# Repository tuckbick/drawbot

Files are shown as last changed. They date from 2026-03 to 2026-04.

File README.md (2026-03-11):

# DrawBot CoreXY Controller & Plotter

## Overview

DrawBot is a custom, ESP32-based controller board and large-format CoreXY pen plotter.

This project was built to scale up the traditional desktop plotter experience. By moving to a custom ESP32 PCB running FluidNC, this iteration eliminates the need for multiple microcontrollers and messy wiring, wrapping WiFi control, SD card hosting, and heavy-duty motor driving into one clean package.

## Project Planning

A "living document" used to keep track of the ongoing planning, component sourcing, and build progress for this project can be found here:

* **[DrawBot Planning Spreadsheet](https://docs.google.com/spreadsheets/d/1DZCe1eKOiRGR80yqyA4uuKFQJ7K6CPcNbJUIT71Rvy4/edit)**

## Inspiration

The first iteration of this build was heavily inspired by the amazing [Plottermap project by Volzo](https://volzo.de/posts/plottermap/).

Volzo's original electronics used a dual-Arduino Nano setup running [GRBL](https://github.com/gnea/grbl/wiki), with a co-processor to handle Stallguard endstops. Since the exact frame specs weren't provided, I reverse-engineered my best guess for the physical construction. For this next-generation build, I am keeping that same physical frame but completely overhauling the electronics to a single-board ESP32 solution.

## The Machine (Hardware)

The physical plotter is designed for large-scale artwork:

* **Frame:** 1m x 1.5m V-Slot extruded aluminum with 3D printed joints.
* **Workspace:** Comfortably accommodates canvases and paper at least 24" x 40".
* **Kinematics:** CoreXY motion system driven by standard belts, pulleys, and idlers.
* **Motors:** 2x NEMA 23 stepper motors for slinging the heavy X/Y gantry, and 1x NEMA 17 for the Z-axis pen lift.
* **External Peripherals:** Support for physical limit switches, a dedicated 24V laser attachment port, and a UART expansion port for future upgrades.

## The Electronics (Controller)

The custom KiCad PCB is designed to be a plug-and-play brain for the machine:

* **Microcontroller:** ESP32 (DevKitC-32).
* **Firmware:** Runs [FluidNC](http://wiki.fluidnc.com/en/home) (a next-gen port of GRBL), which easily handles the CoreXY kinematics and adds native support for TMC SPI configuration.
* **Connectivity:** The ESP32 provides WiFi for remote monitoring and control via a FluidNC web UI.
* **Storage:** An onboard Micro SD card reader hosts the G-code project files locally so your computer doesn't have to stay plugged in for a 10-hour plot.
* **Stepper Drivers:** 3x TMC5160 StepStick modules. These easily provide the juice needed for the NEMA 23 motors.
* **Clean Wiring:** The stepper motor phases are routed out through standard RJ45 jacks, allowing you to use cheap, shielded Cat6 Ethernet cables to wire up the gantry.
* **Power:** Runs on a single 24V power supply (split into motor, laser, and logic domains), stepped down to 5V/3.3V using an MP1584 buck converter.

## Repository Contents

* `/drawbot.kicad_pro` - Main KiCad project file.
* `/*.kicad_sch` - Hierarchical schematic files (Power Delivery, Microcontroller, Stepper Drivers, IO Connectors).
* `/drawbot.kicad_pcb` - The physical PCB layout.
* `/libs/` - Custom footprint and symbol libraries used in the design.
* `/pdf/` - Exported PDF versions of the schematic and PCB layout for quick viewing.

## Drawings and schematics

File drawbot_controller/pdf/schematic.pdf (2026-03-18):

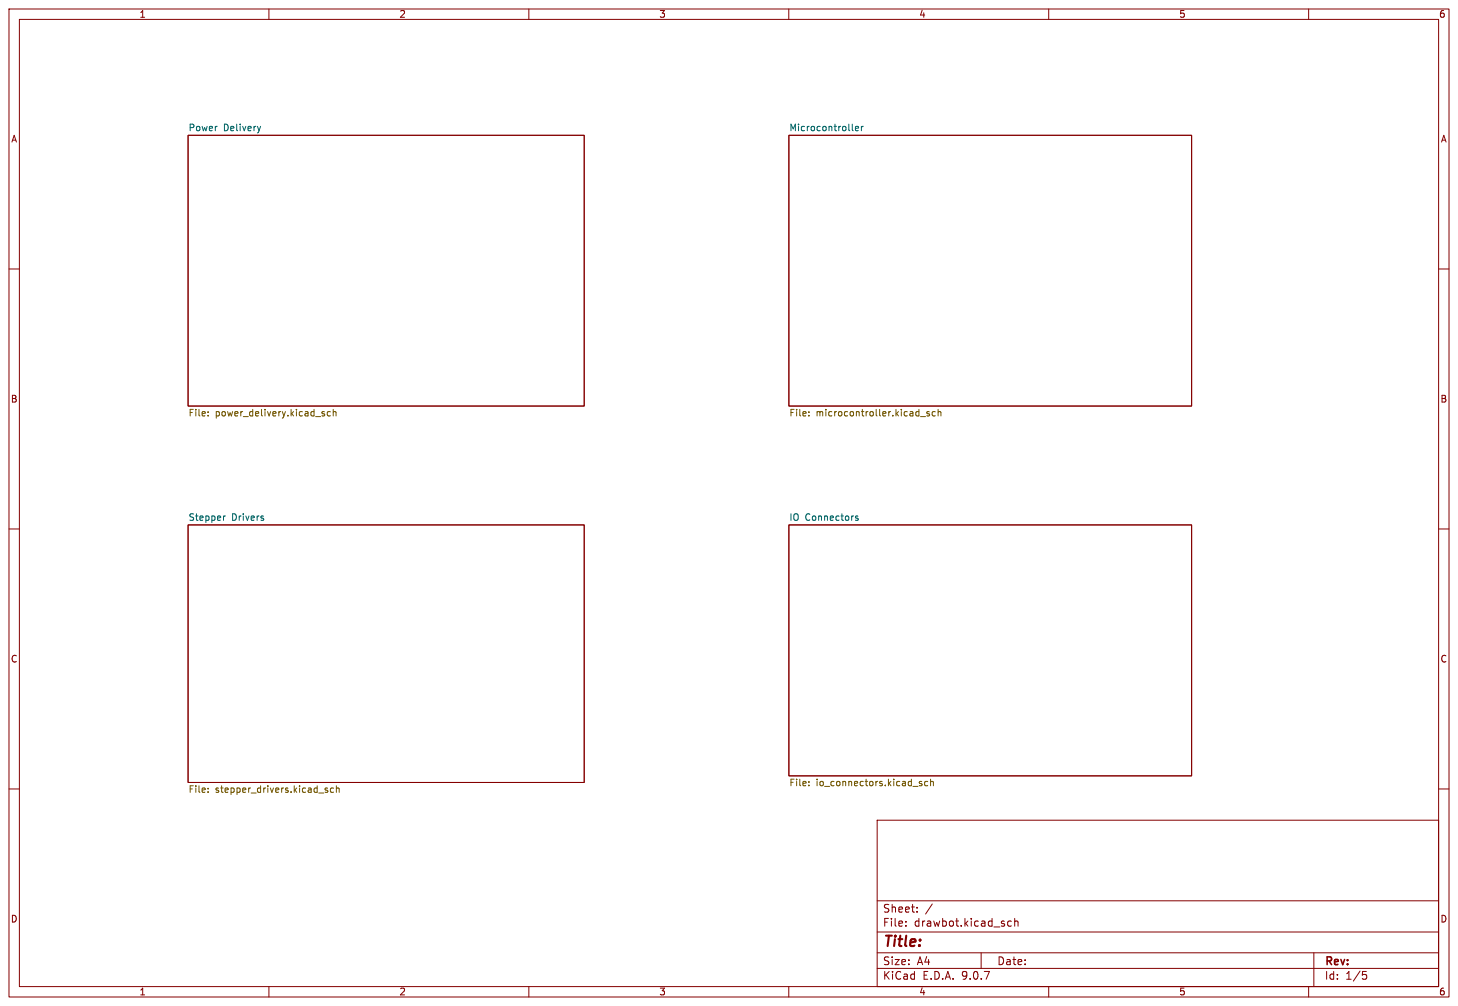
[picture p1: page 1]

IO Connectors File: io_connectors.kicad_sch Stepper Drivers File: stepper_drivers.kicad_sch

Id: 1/5 Title: File: drawbot.kicad_sch Sheet: /

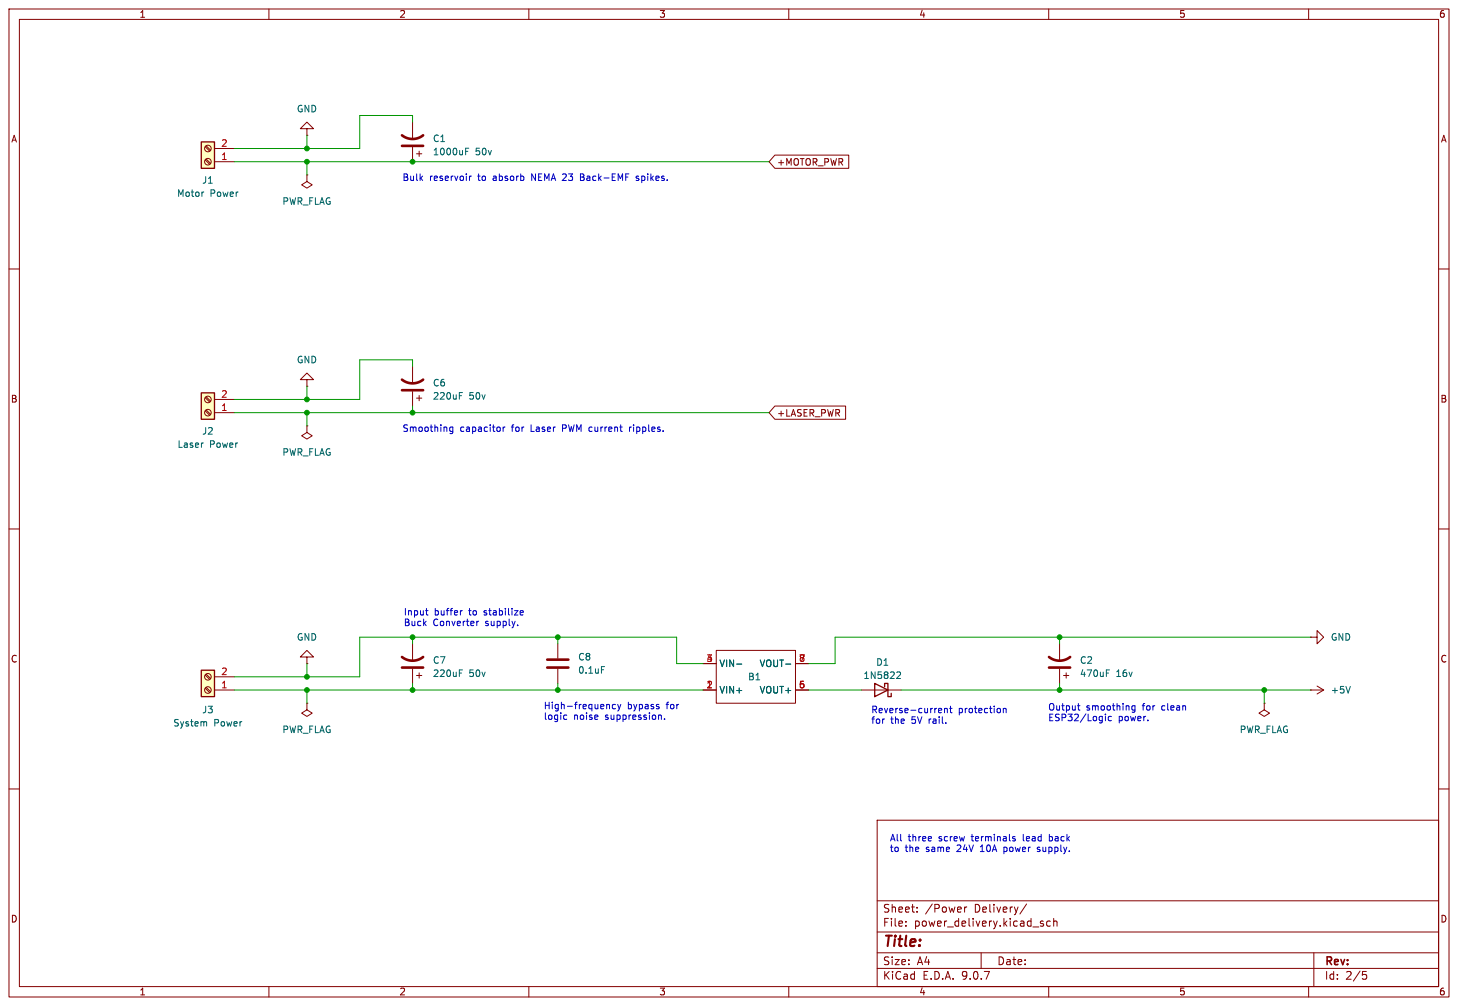
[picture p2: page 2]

Input buffer to stabilize Buck Converter supply.

to the same 24V 10A power supply.

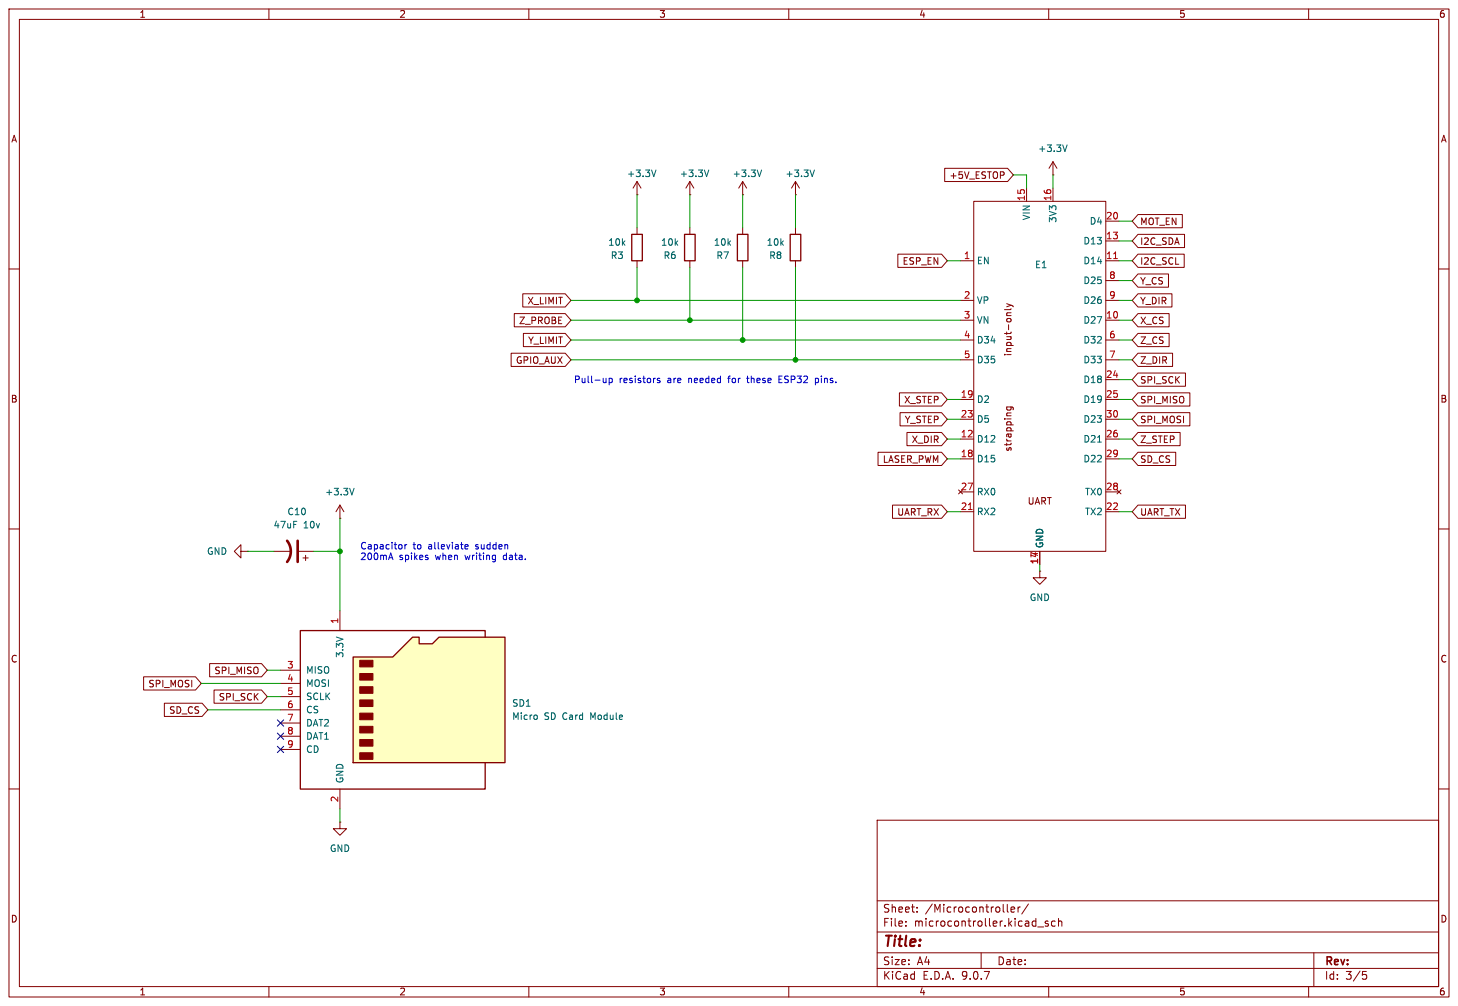
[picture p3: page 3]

Id: 3/5 Title: File: microcontroller.kicad_sch Sheet: /Microcontroller/ GND

2 SD1 Micro SD Card Module GND GND

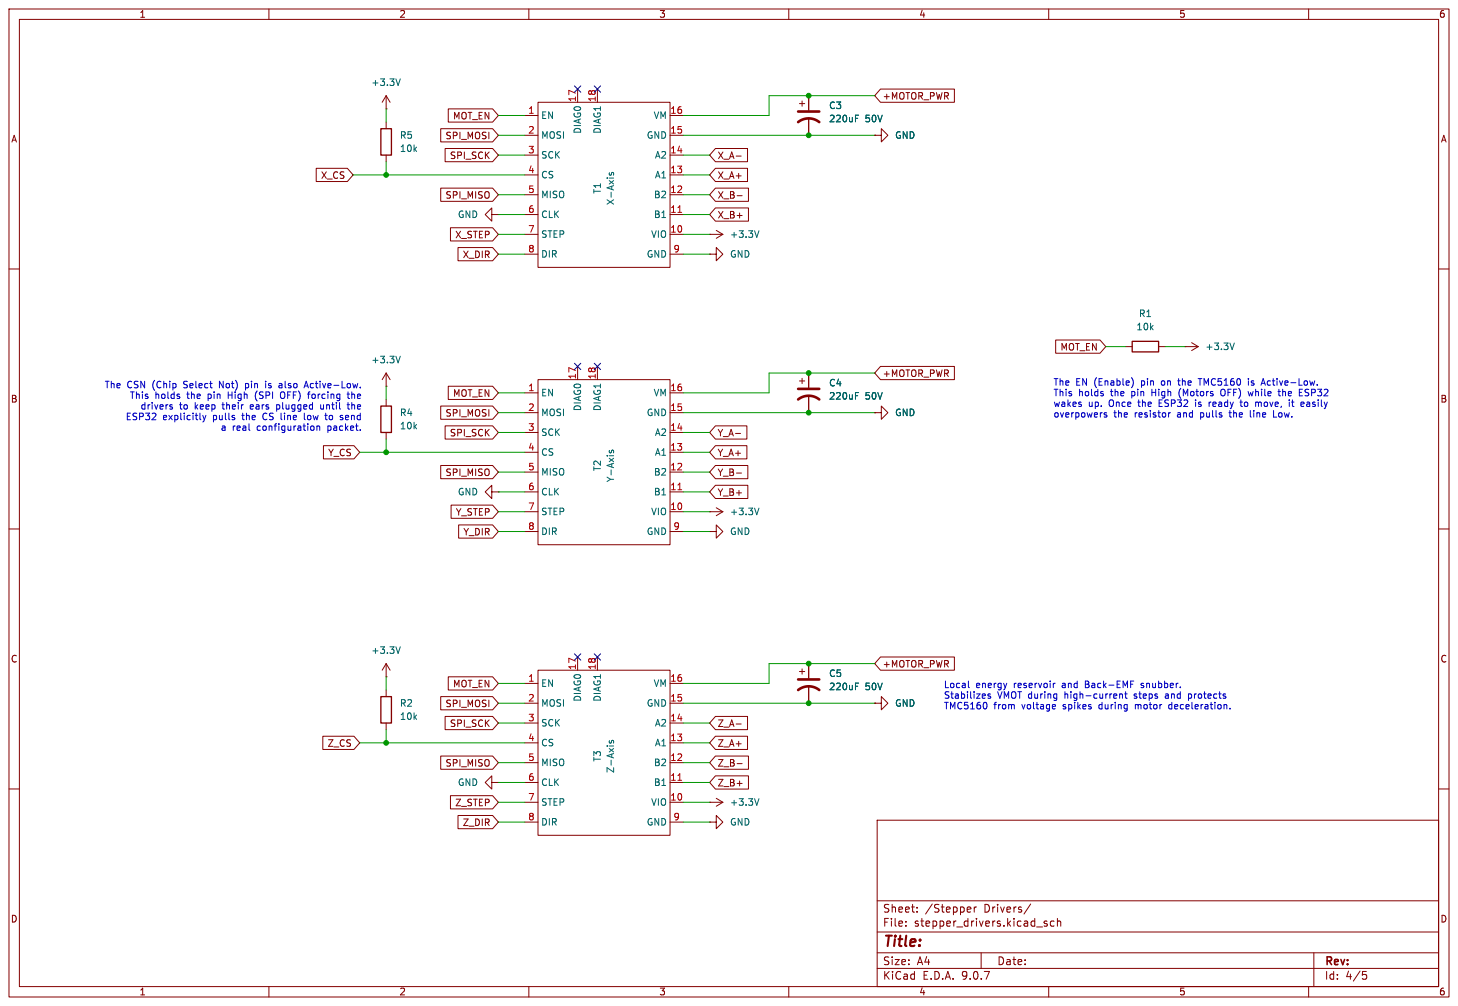
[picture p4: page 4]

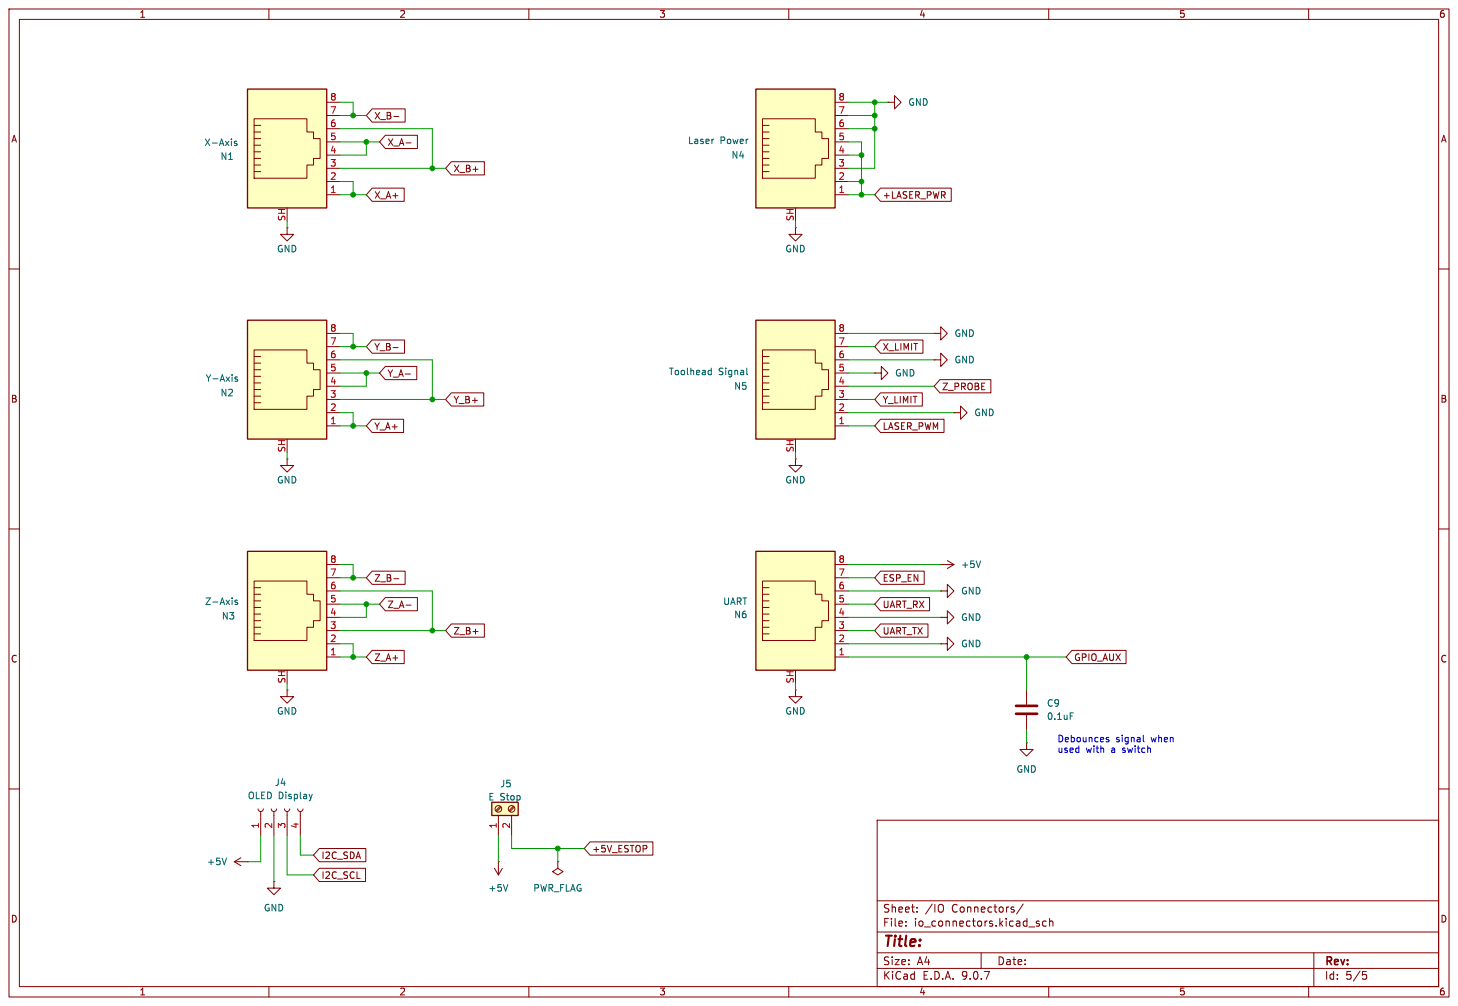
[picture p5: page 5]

Id: 5/5 Title: File: io_connectors.kicad_sch Sheet: /IO Connectors/ 1

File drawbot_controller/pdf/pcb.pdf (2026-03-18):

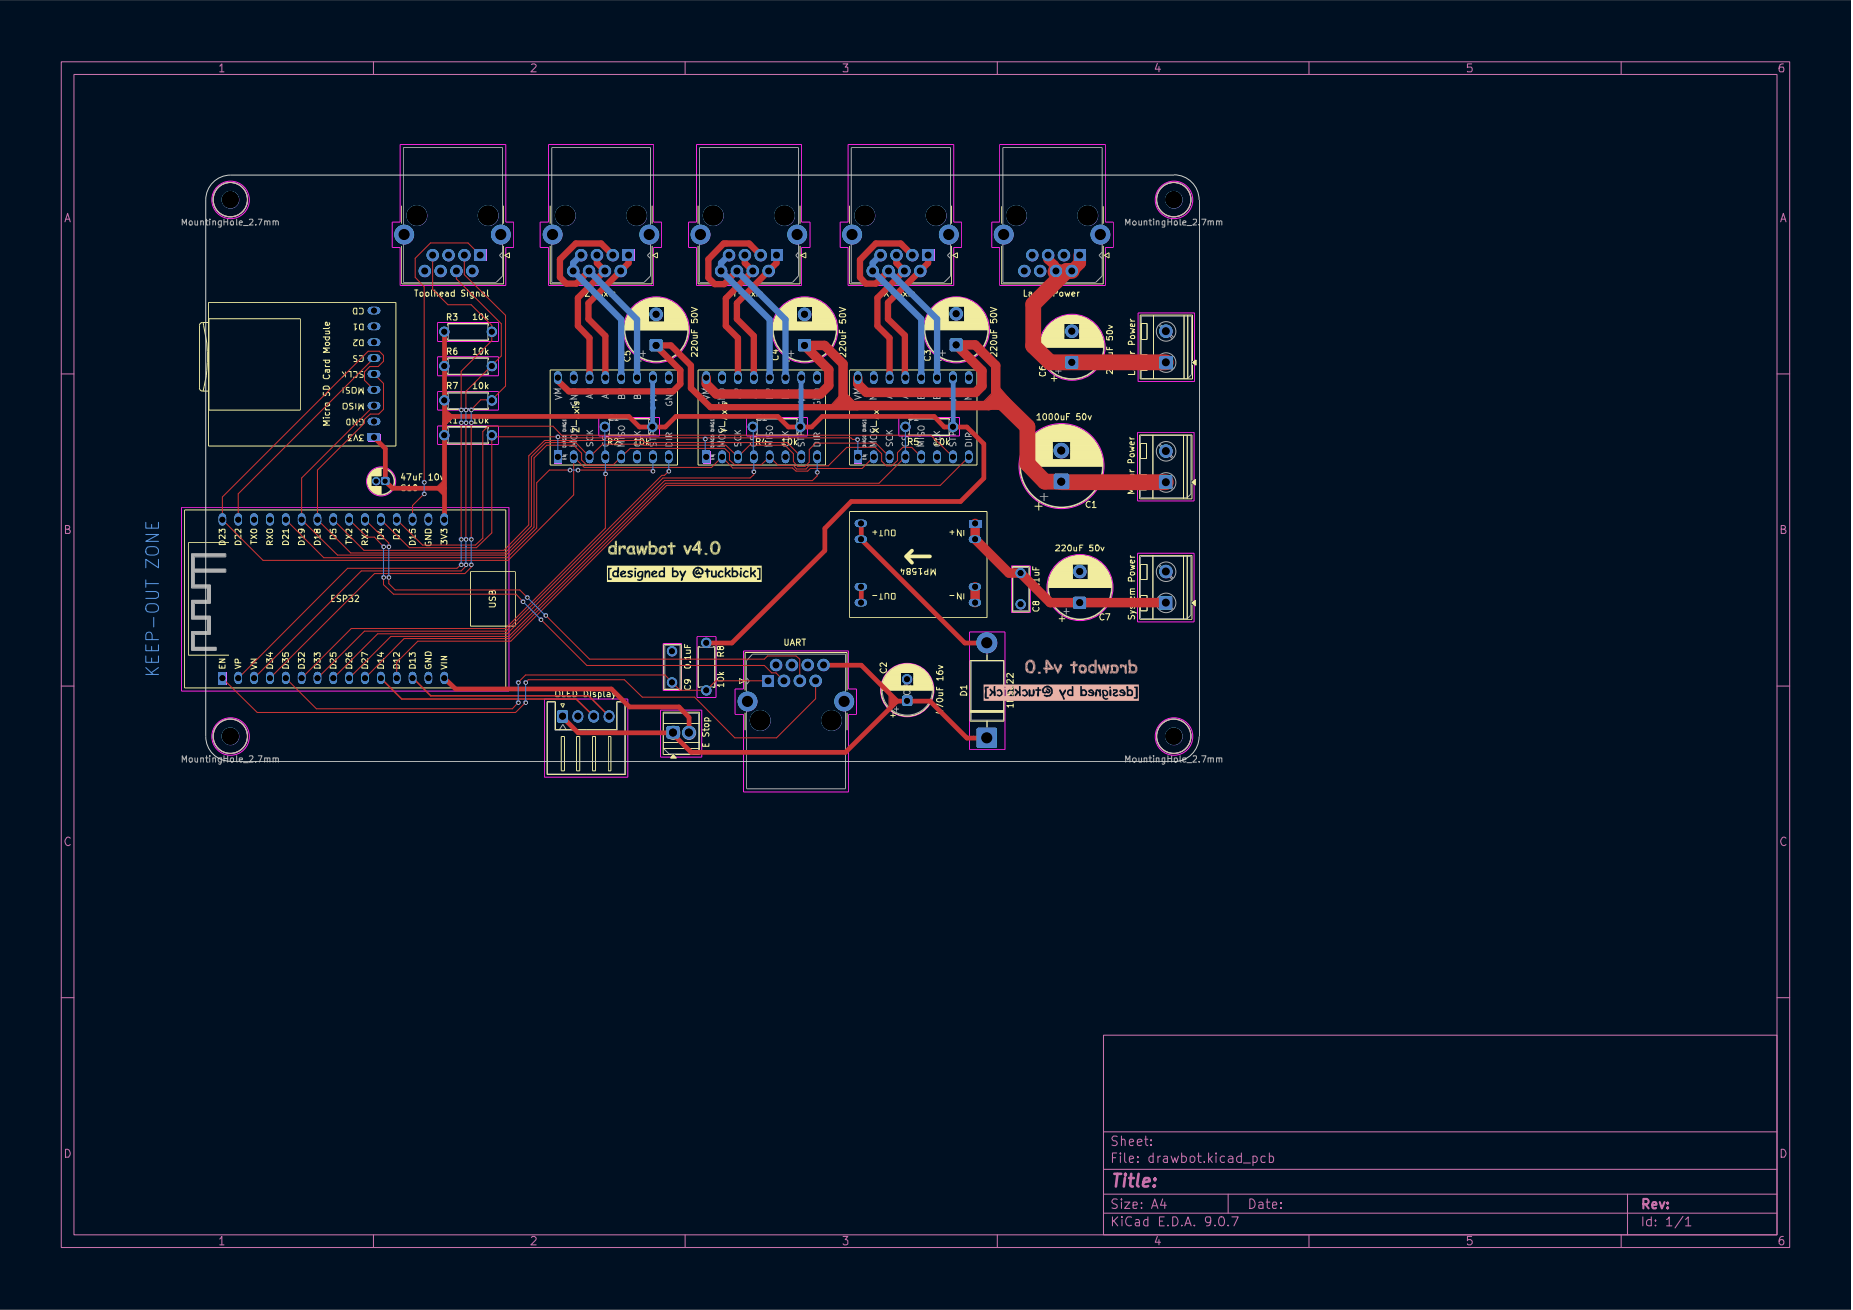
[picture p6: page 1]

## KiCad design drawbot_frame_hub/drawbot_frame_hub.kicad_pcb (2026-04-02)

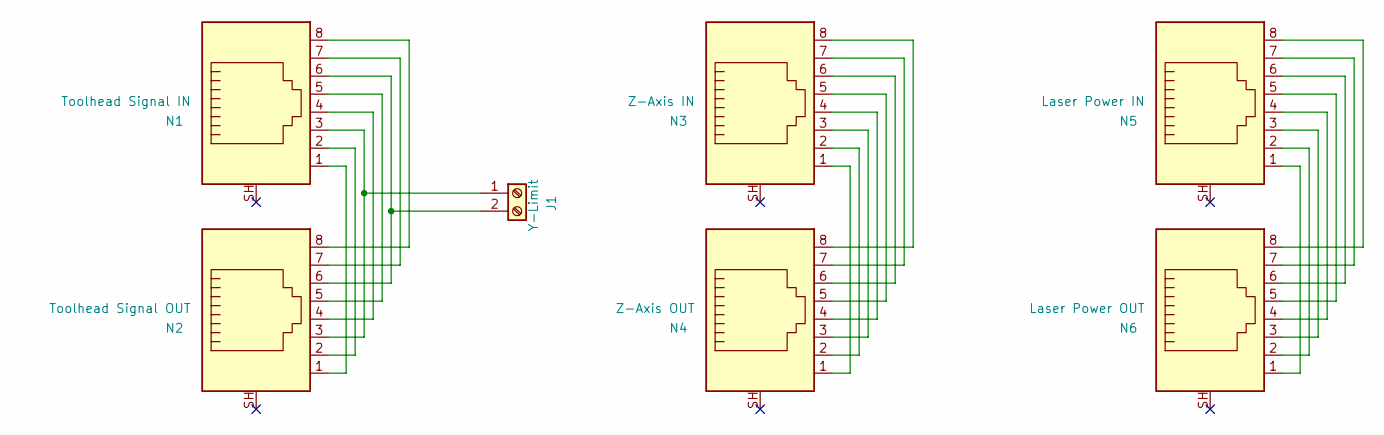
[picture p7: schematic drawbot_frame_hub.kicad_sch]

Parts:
J1: Y-Limit; TerminalBlock_Xinya_XY308-2.54-2P_1x02_P2.54mm_Horizontal
N1: Toolhead Signal IN; RJ45_HALO_HFJ11-x2450HRL_Horizontal
N2: Toolhead Signal OUT; RJ45_HALO_HFJ11-x2450HRL_Horizontal
N3: Z-Axis IN; RJ45_HALO_HFJ11-x2450HRL_Horizontal
N4: Z-Axis OUT; RJ45_HALO_HFJ11-x2450HRL_Horizontal
N5: Laser Power IN; RJ45_HALO_HFJ11-x2450HRL_Horizontal
N6: Laser Power OUT; RJ45_HALO_HFJ11-x2450HRL_Horizontal

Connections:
unnamed: J1.1, N1.3, N2.3
unnamed: J1.2, N1.6, N2.6
unnamed: N1.1, N2.1
unnamed: N1.2, N2.2
unnamed: N1.4, N2.4
unnamed: N1.5, N2.5
unnamed: N1.7, N2.7
unnamed: N1.8, N2.8
unnamed: N3.1, N4.1
unnamed: N3.2, N4.2
unnamed: N3.3, N4.3
unnamed: N3.4, N4.4
unnamed: N3.5, N4.5
unnamed: N3.6, N4.6
unnamed: N3.7, N4.7
unnamed: N3.8, N4.8
unnamed: N5.1, N6.1
unnamed: N5.2, N6.2
unnamed: N5.3, N6.3
unnamed: N5.4, N6.4
unnamed: N5.5, N6.5
unnamed: N5.6, N6.6
unnamed: N5.7, N6.7
unnamed: N5.8, N6.8

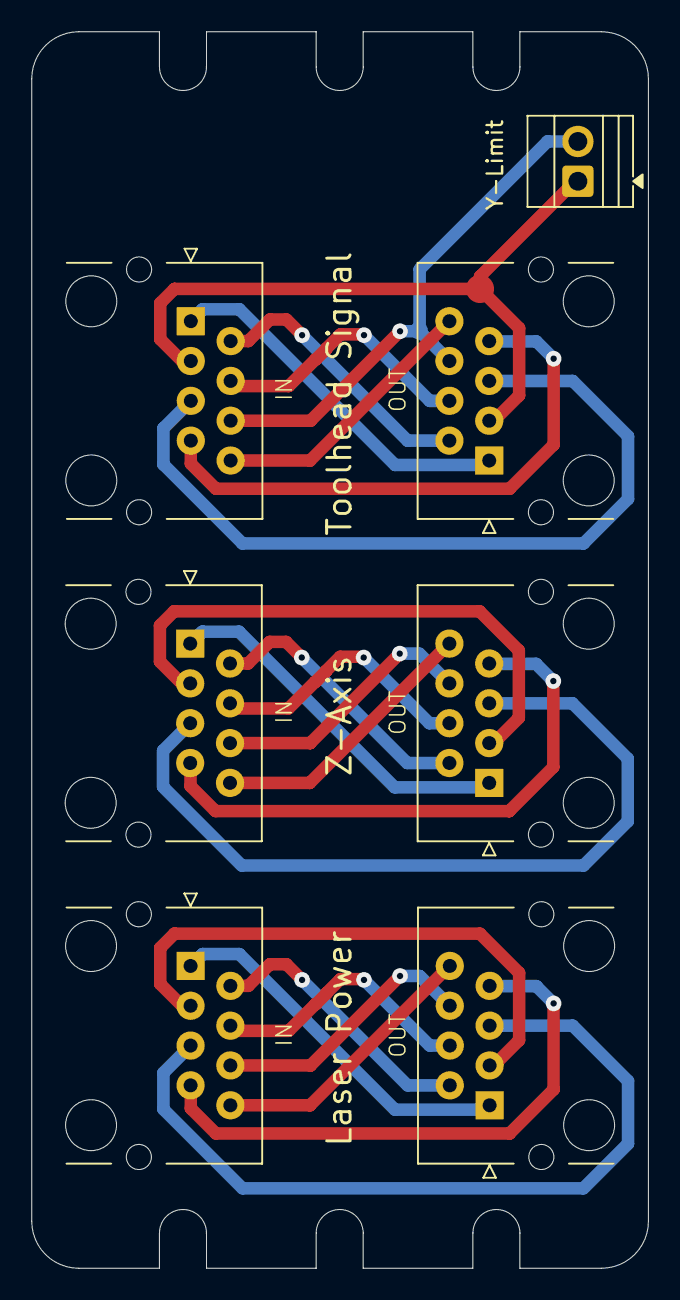
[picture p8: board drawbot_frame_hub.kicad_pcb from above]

Board: 2 copper layers, 39.3 x 78.9 mm, 7 parts (0 on the bottom side), 24 nets.

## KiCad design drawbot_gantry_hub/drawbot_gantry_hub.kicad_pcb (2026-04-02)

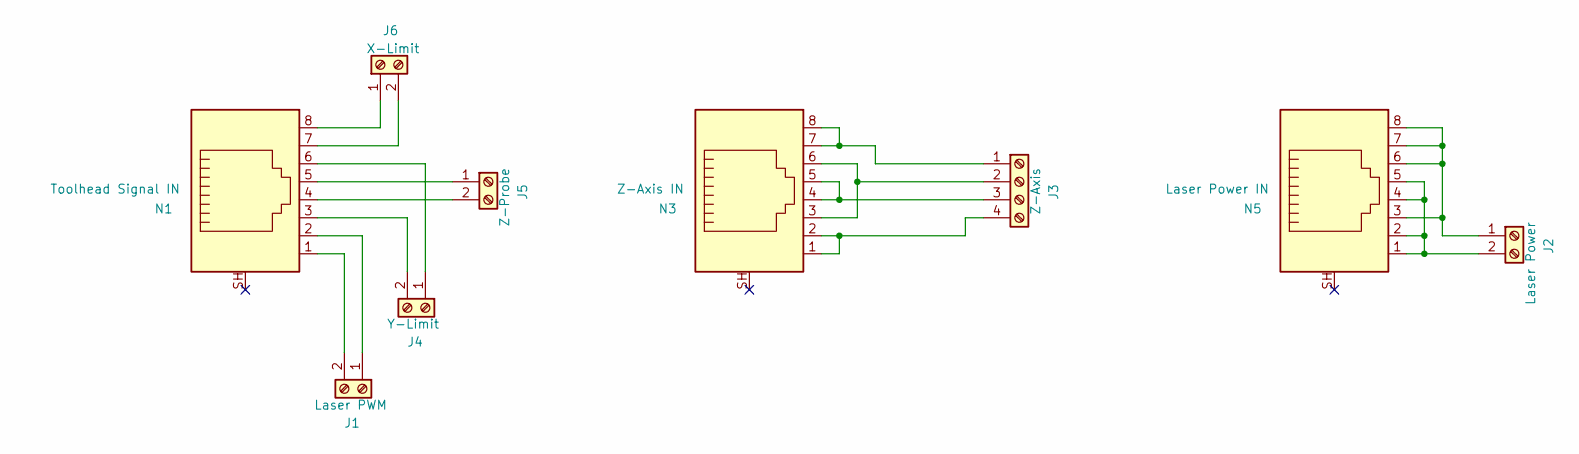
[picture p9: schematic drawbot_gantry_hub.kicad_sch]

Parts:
J1: Laser PWM; TerminalBlock_Xinya_XY308-2.54-2P_1x02_P2.54mm_Horizontal
J2: Laser Power; TerminalBlock_RND_205-00045_1x02_P5.00mm_Horizontal
J3: Z-Axis; TerminalBlock_RND_205-00047_1x04_P5.00mm_Horizontal
J4: Y-Limit; TerminalBlock_Xinya_XY308-2.54-2P_1x02_P2.54mm_Horizontal
J5: Z-Probe; TerminalBlock_Xinya_XY308-2.54-2P_1x02_P2.54mm_Horizontal
J6: X-Limit; TerminalBlock_Xinya_XY308-2.54-2P_1x02_P2.54mm_Horizontal
N1: Toolhead Signal IN; RJ45_HALO_HFJ11-x2450HRL_Horizontal
N3: Z-Axis IN; RJ45_HALO_HFJ11-x2450HRL_Horizontal
N5: Laser Power IN; RJ45_HALO_HFJ11-x2450HRL_Horizontal

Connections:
unnamed: J1.1, N1.2
unnamed: J1.2, N1.1
unnamed: J2.1, N5.3, N5.6, N5.7, N5.8
unnamed: J2.2, N5.1, N5.2, N5.4, N5.5
unnamed: J3.1, N3.7, N3.8
unnamed: J3.2, N3.3, N3.6
unnamed: J3.3, N3.4, N3.5
unnamed: J3.4, N3.1, N3.2
unnamed: J4.1, N1.6
unnamed: J4.2, N1.3
unnamed: J5.1, N1.5
unnamed: J5.2, N1.4
unnamed: J6.1, N1.8
unnamed: J6.2, N1.7

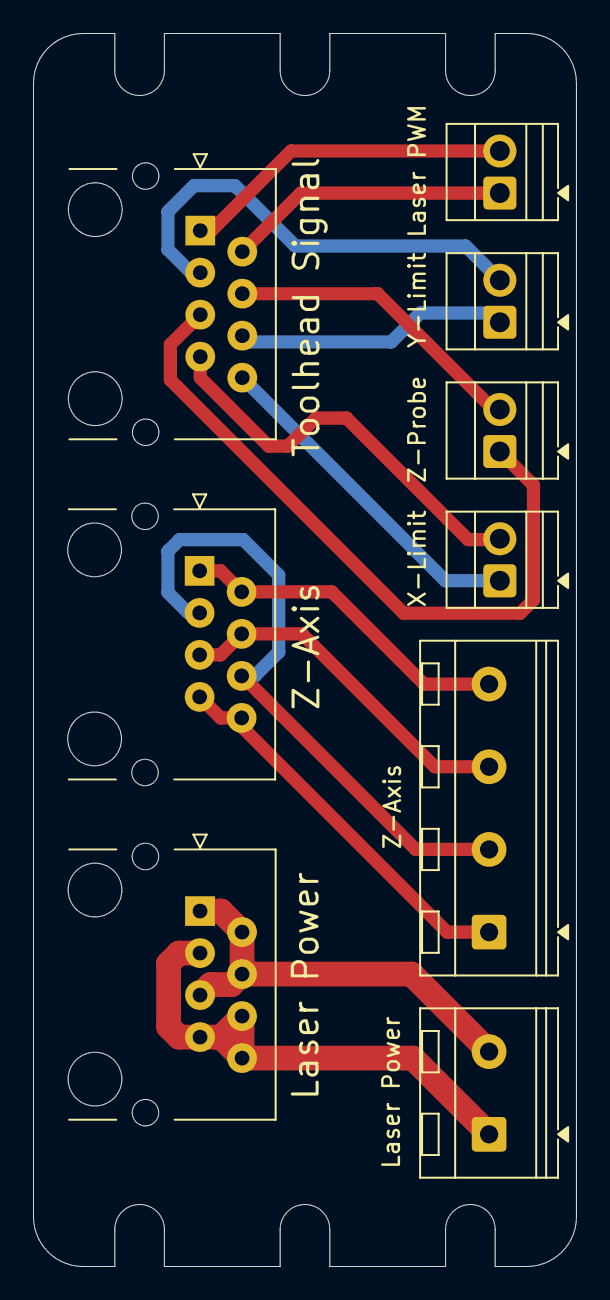
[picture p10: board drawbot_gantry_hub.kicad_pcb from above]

Board: 2 copper layers, 32.8 x 74.5 mm, 9 parts (0 on the bottom side), 14 nets.

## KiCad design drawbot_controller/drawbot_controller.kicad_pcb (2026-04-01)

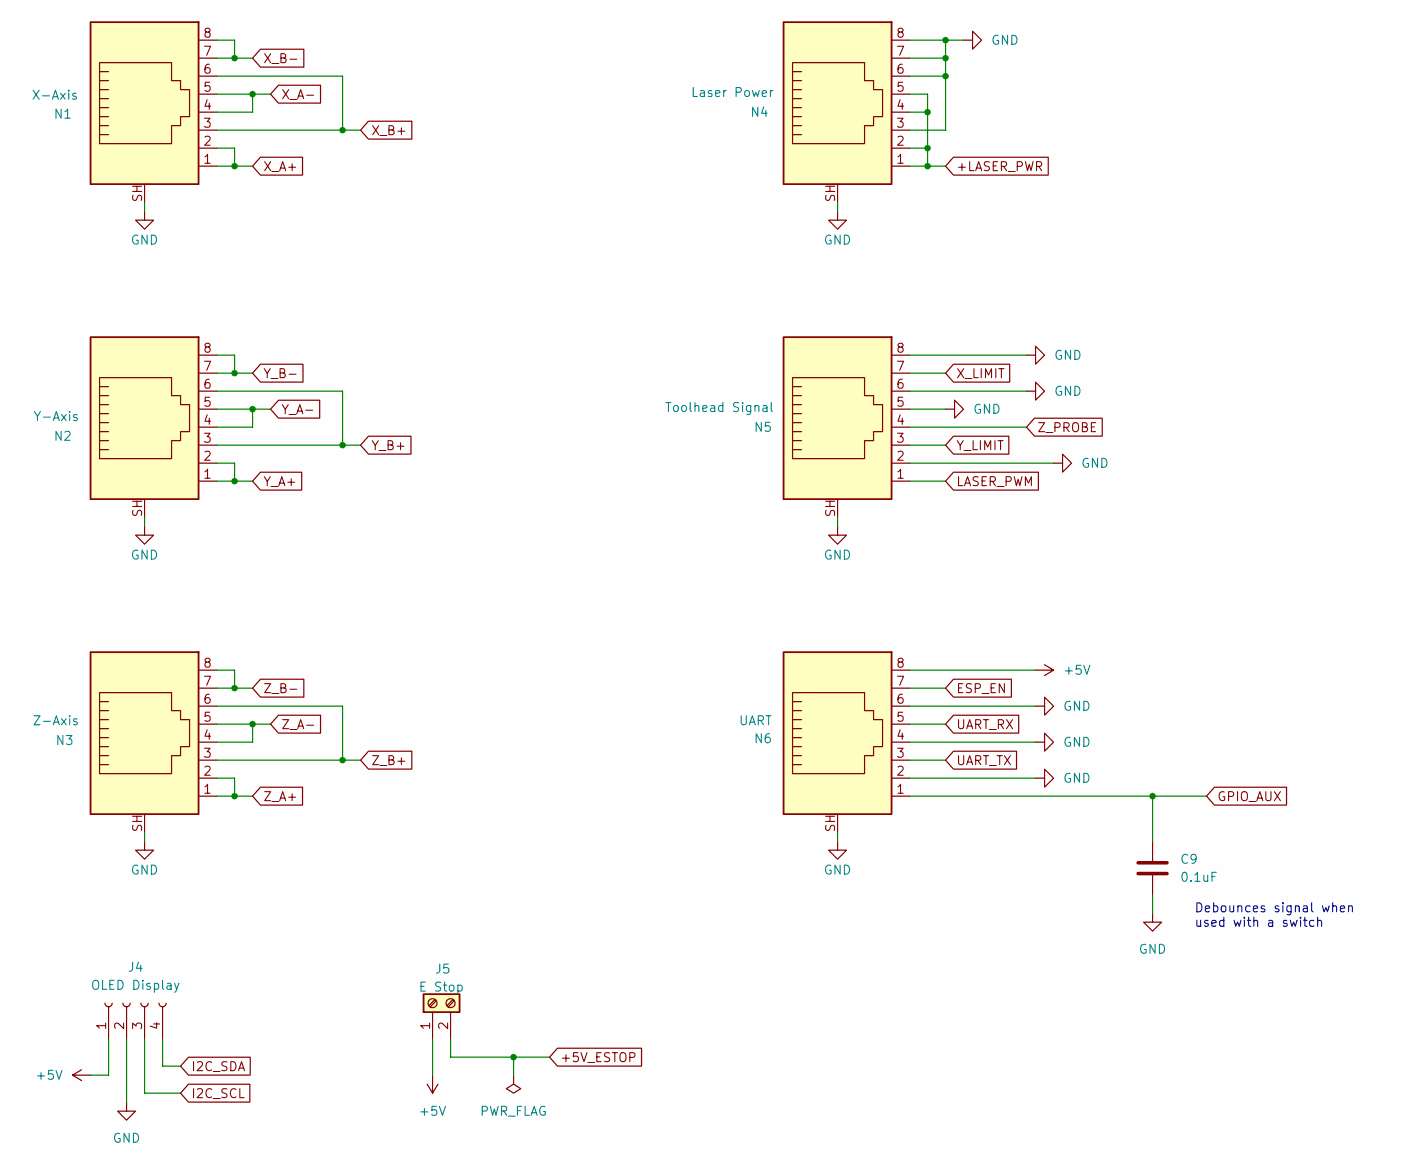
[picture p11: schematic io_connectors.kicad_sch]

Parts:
C9: 0.1uF; C_Rect_L7.0mm_W2.5mm_P5.00mm
J4: OLED Display; JST_XH_S4B-XH-A_1x04_P2.50mm_Horizontal
J5: E Stop; TerminalBlock_Xinya_XY308-2.54-2P_1x02_P2.54mm_Horizontal
N1: X-Axis; RJ45_HALO_HFJ11-x2450HRL_Horizontal
N2: Y-Axis; RJ45_HALO_HFJ11-x2450HRL_Horizontal
N3: Z-Axis; RJ45_HALO_HFJ11-x2450HRL_Horizontal
N4: Laser Power; RJ45_HALO_HFJ11-x2450HRL_Horizontal
N5: Toolhead Signal; RJ45_HALO_HFJ11-x2450HRL_Horizontal
N6: UART; RJ45_HALO_HFJ11-x2450HRL_Horizontal

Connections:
+5V: J4.1, J5.1, N6.8; also elsewhere on the board
+5V_ESTOP: J5.2; also elsewhere on the board
+LASER_PWR: N4.1, N4.2, N4.4, N4.5; also elsewhere on the board
ESP_EN: N6.7; also elsewhere on the board
GND: C9.2, J4.2, N1.SH, N2.SH, N3.SH, N4.3, N4.6, N4.7, N4.8, N4.SH, N5.2, N5.5, N5.6, N5.8, N5.SH, N6.2, N6.4, N6.6, N6.SH; also elsewhere on the board
GPIO_AUX: C9.1, N6.1; also elsewhere on the board
I2C_SCL: J4.3; also elsewhere on the board
I2C_SDA: J4.4; also elsewhere on the board
LASER_PWM: N5.1; also elsewhere on the board
UART_RX: N6.5; also elsewhere on the board
UART_TX: N6.3; also elsewhere on the board
X_A+: N1.1, N1.2; also elsewhere on the board
X_A-: N1.4, N1.5; also elsewhere on the board
X_B+: N1.3, N1.6; also elsewhere on the board
X_B-: N1.7, N1.8; also elsewhere on the board
X_LIMIT: N5.7; also elsewhere on the board
Y_A+: N2.1, N2.2; also elsewhere on the board
Y_A-: N2.4, N2.5; also elsewhere on the board
Y_B+: N2.3, N2.6; also elsewhere on the board
Y_B-: N2.7, N2.8; also elsewhere on the board
Y_LIMIT: N5.3; also elsewhere on the board
Z_A+: N3.1, N3.2; also elsewhere on the board
Z_A-: N3.4, N3.5; also elsewhere on the board
Z_B+: N3.3, N3.6; also elsewhere on the board
Z_B-: N3.7, N3.8; also elsewhere on the board
Z_PROBE: N5.4; also elsewhere on the board

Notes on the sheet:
Debounces signal when used with a switch

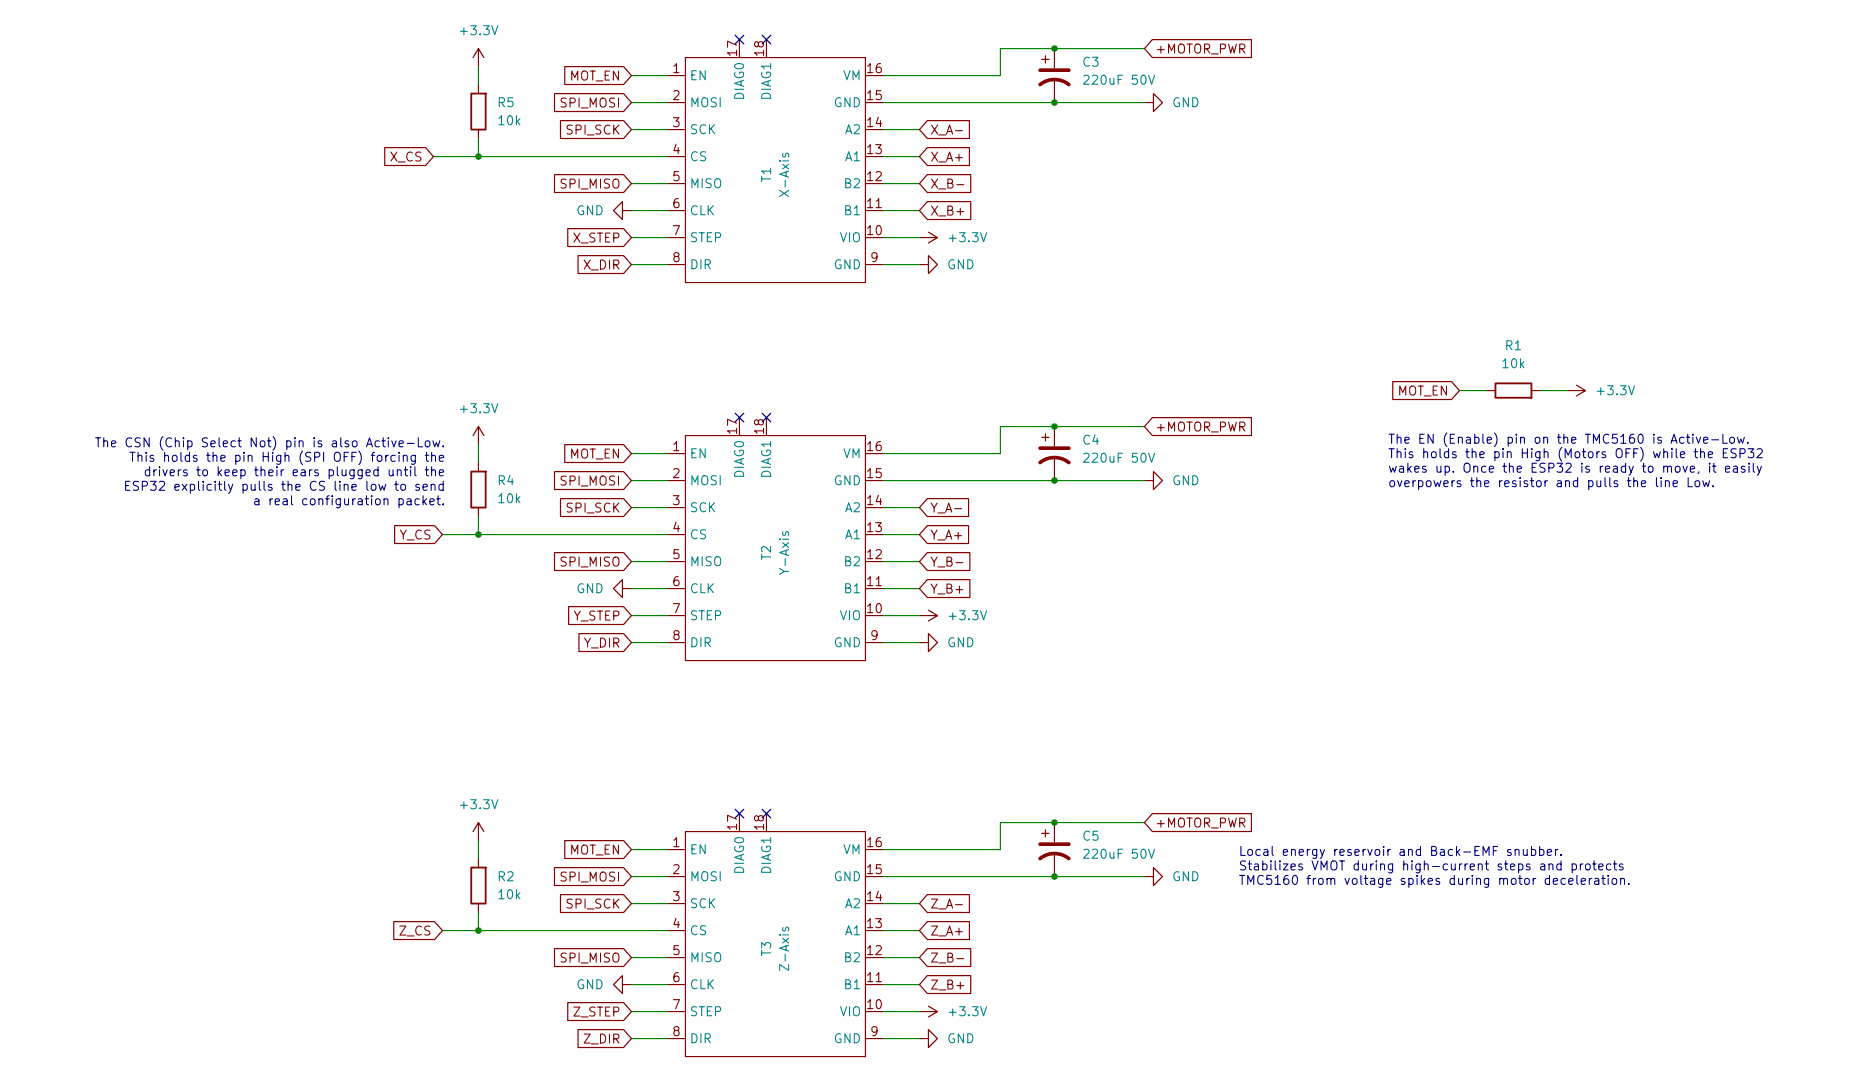
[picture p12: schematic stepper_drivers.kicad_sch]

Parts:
C3, C4, C5: 220uF 50V; CP_Radial_D10.0mm_P5.00mm
R1, R2, R4, R5: 10k; R_Axial_DIN0207_L6.3mm_D2.5mm_P7.62mm_Horizontal
T1: X-Axis; TMC5160
T2: Y-Axis; TMC5160
T3: Z-Axis; TMC5160

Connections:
+3.3V: R1.2, R2.2, R4.2, R5.2, T1.10 (VIO), T2.10 (VIO), T3.10 (VIO); also elsewhere on the board
+MOTOR_PWR: C3.1, C4.1, C5.1, T1.16 (VM), T2.16 (VM), T3.16 (VM); also elsewhere on the board
GND: C3.2, C4.2, C5.2, T1.6 (CLK), T1.9 (GND), T1.15 (GND), T2.6 (CLK), T2.9 (GND), T2.15 (GND), T3.6 (CLK), T3.9 (GND), T3.15 (GND); also elsewhere on the board
MOT_EN: R1.1, T1.1 (EN), T2.1 (EN), T3.1 (EN); also elsewhere on the board
SPI_MISO: T1.5 (MISO), T2.5 (MISO), T3.5 (MISO); also elsewhere on the board
SPI_MOSI: T1.2 (MOSI), T2.2 (MOSI), T3.2 (MOSI); also elsewhere on the board
SPI_SCK: T1.3 (SCK), T2.3 (SCK), T3.3 (SCK); also elsewhere on the board
X_A+: T1.13 (A1); also elsewhere on the board
X_A-: T1.14 (A2); also elsewhere on the board
X_B+: T1.11 (B1); also elsewhere on the board
X_B-: T1.12 (B2); also elsewhere on the board
X_CS: R5.1, T1.4 (CS); also elsewhere on the board
X_DIR: T1.8 (DIR); also elsewhere on the board
X_STEP: T1.7 (STEP); also elsewhere on the board
Y_A+: T2.13 (A1); also elsewhere on the board
Y_A-: T2.14 (A2); also elsewhere on the board
Y_B+: T2.11 (B1); also elsewhere on the board
Y_B-: T2.12 (B2); also elsewhere on the board
Y_CS: R4.1, T2.4 (CS); also elsewhere on the board
Y_DIR: T2.8 (DIR); also elsewhere on the board
Y_STEP: T2.7 (STEP); also elsewhere on the board
Z_A+: T3.13 (A1); also elsewhere on the board
Z_A-: T3.14 (A2); also elsewhere on the board
Z_B+: T3.11 (B1); also elsewhere on the board
Z_B-: T3.12 (B2); also elsewhere on the board
Z_CS: R2.1, T3.4 (CS); also elsewhere on the board
Z_DIR: T3.8 (DIR); also elsewhere on the board
Z_STEP: T3.7 (STEP); also elsewhere on the board

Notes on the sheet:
The CSN (Chip Select Not) pin is also Active-Low. This holds the pin High (SPI OFF) forcing the drivers to keep their ears plugged until the ESP32 explicitly pulls the CS line low to send a real configuration packet.
Local energy reservoir and Back-EMF snubber. Stabilizes VMOT during high-current steps and protects TMC5160 from voltage spikes during motor deceleration.
The EN (Enable) pin on the TMC5160 is Active-Low. This holds the pin High (Motors OFF) while the ESP32 wakes up. Once the ESP32 is ready to move, it easily overpowers the resistor and pulls the line Low.

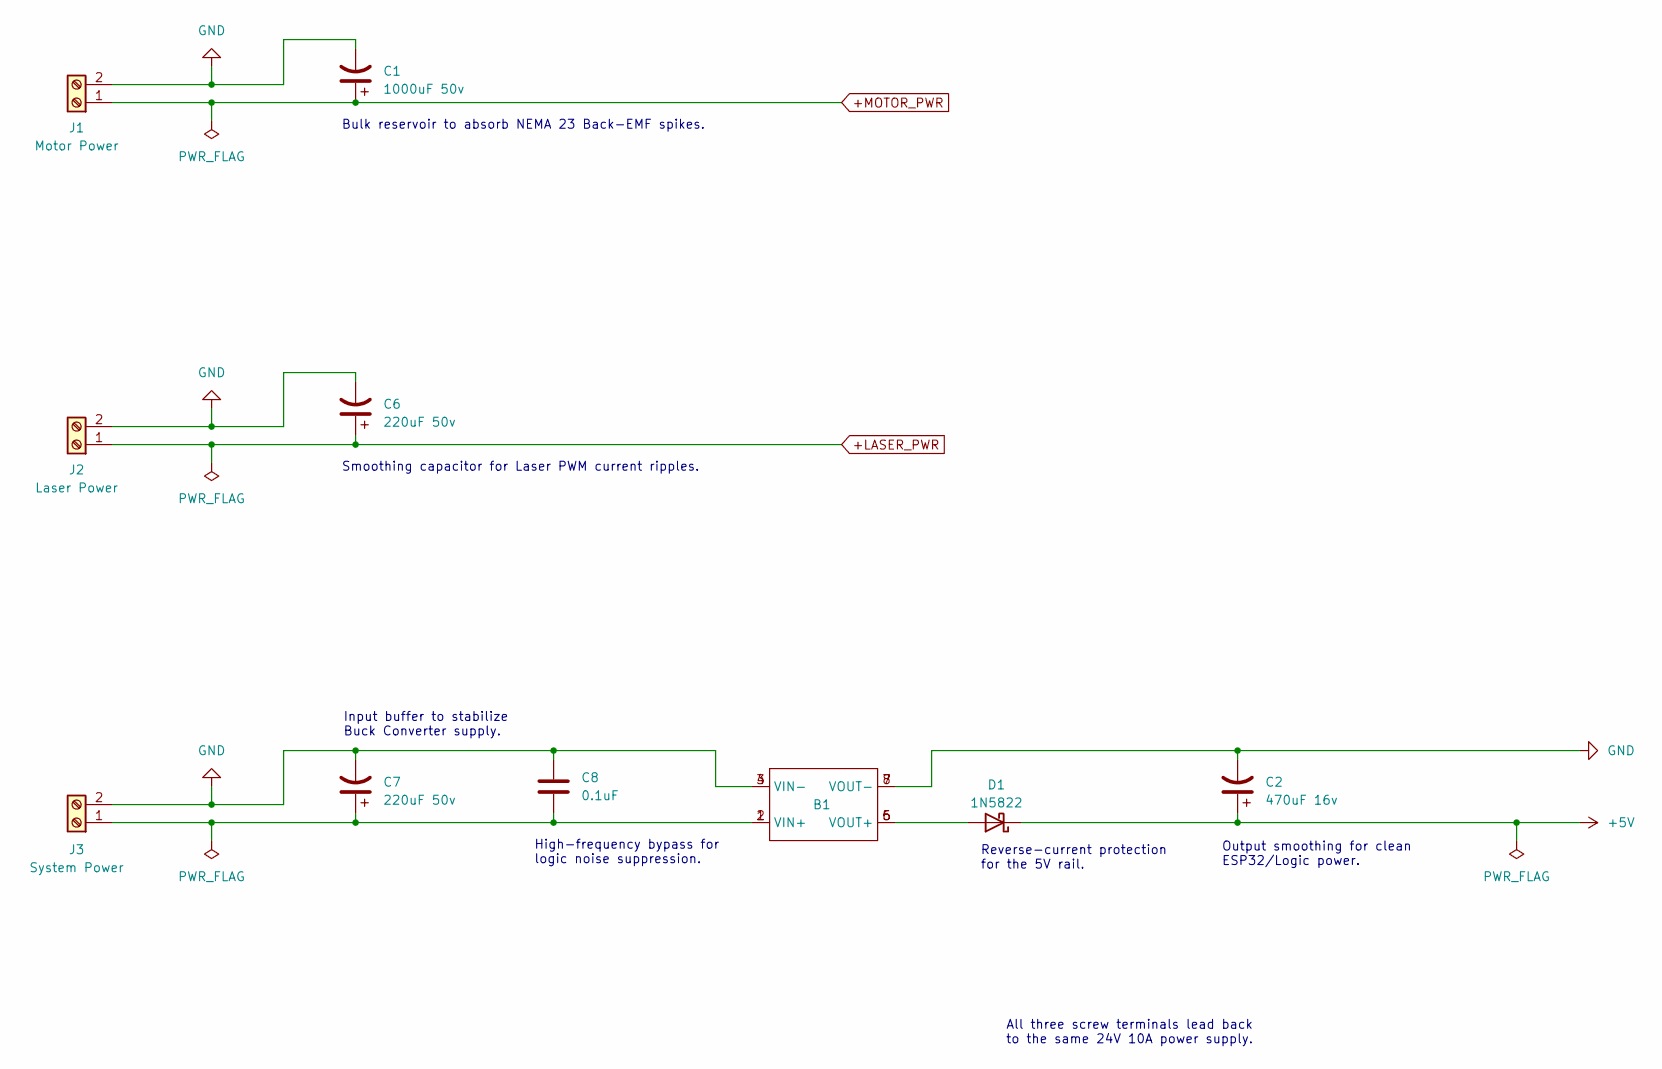
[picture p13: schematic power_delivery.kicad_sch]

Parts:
B1: MP1584
C1: 1000uF 50v; CP_Radial_D13.0mm_P5.00mm
C2: 470uF 16v; CP_Radial_D8.0mm_P3.50mm
C6, C7: 220uF 50v; CP_Radial_D10.0mm_P5.00mm
C8: 0.1uF; C_Rect_L7.0mm_W2.5mm_P5.00mm
D1: 1N5822; D_DO-201AD_P15.24mm_Horizontal
J1: Motor Power; TerminalBlock_RND_205-00045_1x02_P5.00mm_Horizontal
J2: Laser Power; TerminalBlock_RND_205-00045_1x02_P5.00mm_Horizontal
J3: System Power; TerminalBlock_RND_205-00045_1x02_P5.00mm_Horizontal

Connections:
+5V: C2.1, D1.1 (K); also elsewhere on the board
+LASER_PWR: C6.1, J2.1; also elsewhere on the board
+MOTOR_PWR: C1.1, J1.1; also elsewhere on the board
GND: B1.3 (VIN-), B1.4 (VIN-), B1.7 (VOUT-), B1.8 (VOUT-), C1.2, C2.2, C6.2, C7.2, C8.1, J1.2, J2.2, J3.2; also elsewhere on the board
unnamed: B1.5 (VOUT+), B1.6 (VOUT+), D1.2 (A)
unnamed: B1.1 (VIN+), B1.2 (VIN+), C7.1, C8.2, J3.1

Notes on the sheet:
All three screw terminals lead back to the same 24V 10A power supply.
Input buffer to stabilize Buck Converter supply.
Bulk reservoir to absorb NEMA 23 Back-EMF spikes.
Smoothing capacitor for Laser PWM current ripples.
Reverse-current protection for the 5V rail.
High-frequency bypass for logic noise suppression.
Output smoothing for clean ESP32/Logic power.

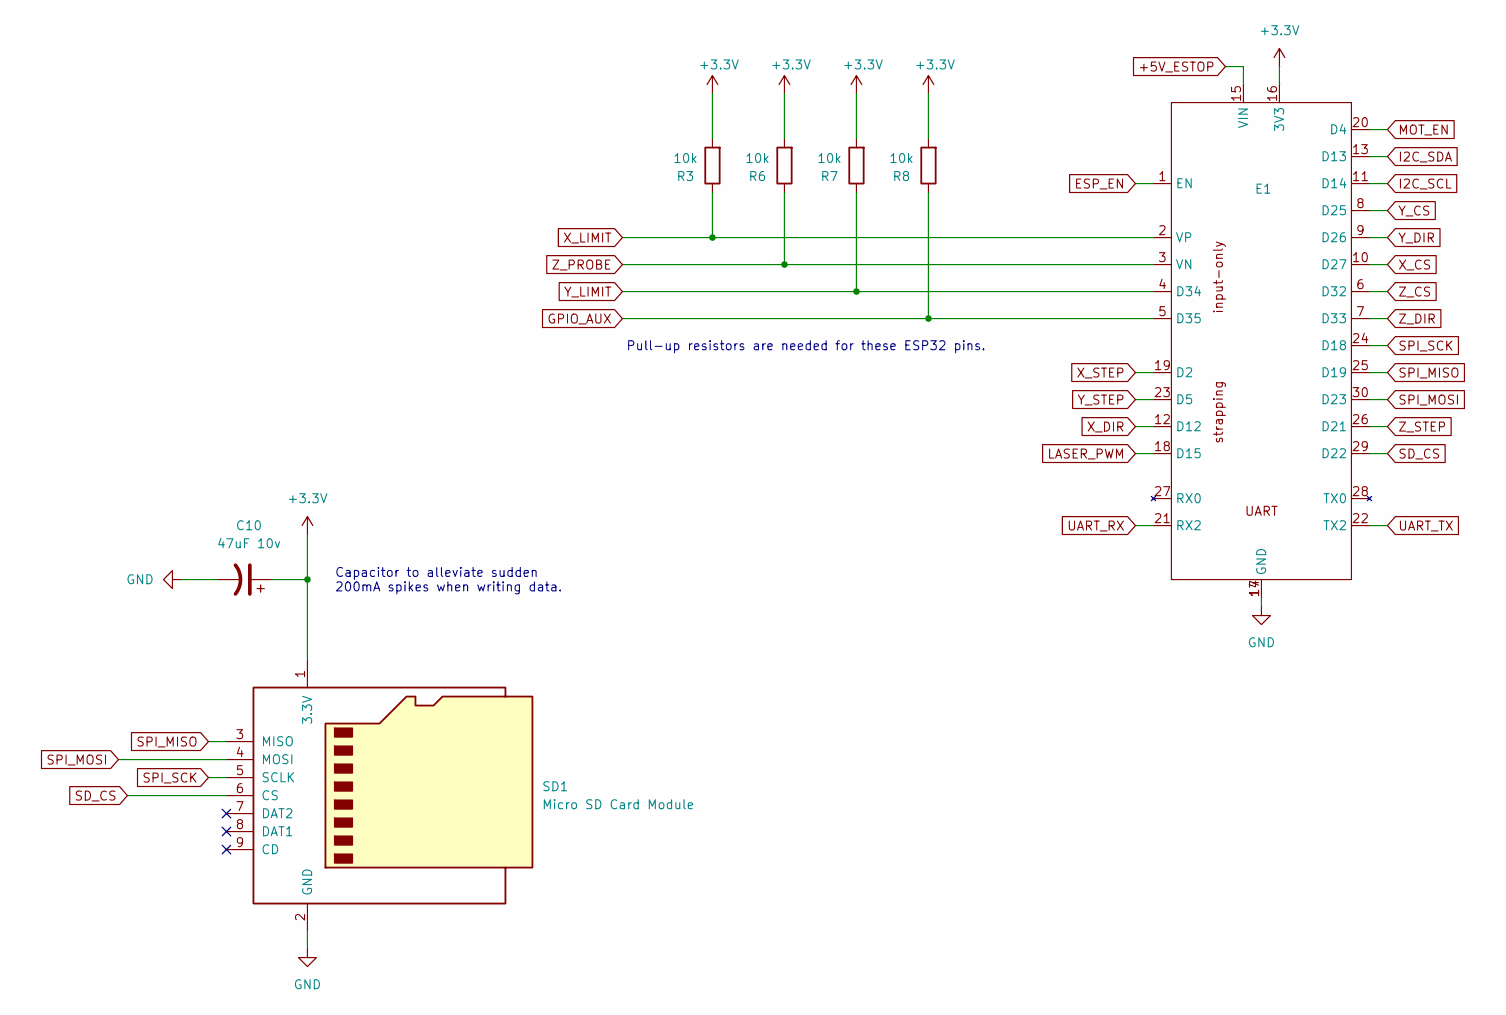
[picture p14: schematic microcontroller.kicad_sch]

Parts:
C10: 47uF 10v; CP_Radial_D4.0mm_P1.50mm
E1: ESP32; ESP32-DevKitC-32
R3, R6, R7, R8: 10k; R_Axial_DIN0207_L6.3mm_D2.5mm_P7.62mm_Horizontal
SD1: Micro SD Card Module

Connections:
+3.3V: C10.1, E1.16 (3V3), R3.2, R6.2, R7.2, R8.2, SD1.1 (3.3V); also elsewhere on the board
+5V_ESTOP: E1.15 (VIN); also elsewhere on the board
ESP_EN: E1.1 (EN); also elsewhere on the board
GND: C10.2, E1.14 (GND), E1.17 (GND), SD1.2 (GND); also elsewhere on the board
GPIO_AUX: E1.5 (D35), R8.1; also elsewhere on the board
I2C_SCL: E1.11 (D14); also elsewhere on the board
I2C_SDA: E1.13 (D13); also elsewhere on the board
LASER_PWM: E1.18 (D15); also elsewhere on the board
MOT_EN: E1.20 (D4); also elsewhere on the board
SD_CS: E1.29 (D22), SD1.6 (CS)
SPI_MISO: E1.25 (D19), SD1.3 (MISO); also elsewhere on the board
SPI_MOSI: E1.30 (D23), SD1.4 (MOSI); also elsewhere on the board
SPI_SCK: E1.24 (D18), SD1.5 (SCLK); also elsewhere on the board
UART_RX: E1.21 (RX2); also elsewhere on the board
UART_TX: E1.22 (TX2); also elsewhere on the board
X_CS: E1.10 (D27); also elsewhere on the board
X_DIR: E1.12 (D12); also elsewhere on the board
X_LIMIT: E1.2 (VP), R3.1; also elsewhere on the board
X_STEP: E1.19 (D2); also elsewhere on the board
Y_CS: E1.8 (D25); also elsewhere on the board
Y_DIR: E1.9 (D26); also elsewhere on the board
Y_LIMIT: E1.4 (D34), R7.1; also elsewhere on the board
Y_STEP: E1.23 (D5); also elsewhere on the board
Z_CS: E1.6 (D32); also elsewhere on the board
Z_DIR: E1.7 (D33); also elsewhere on the board
Z_PROBE: E1.3 (VN), R6.1; also elsewhere on the board
Z_STEP: E1.26 (D21); also elsewhere on the board

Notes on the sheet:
Pull-up resistors are needed for these ESP32 pins.
Capacitor to alleviate sudden 200mA spikes when writing data.

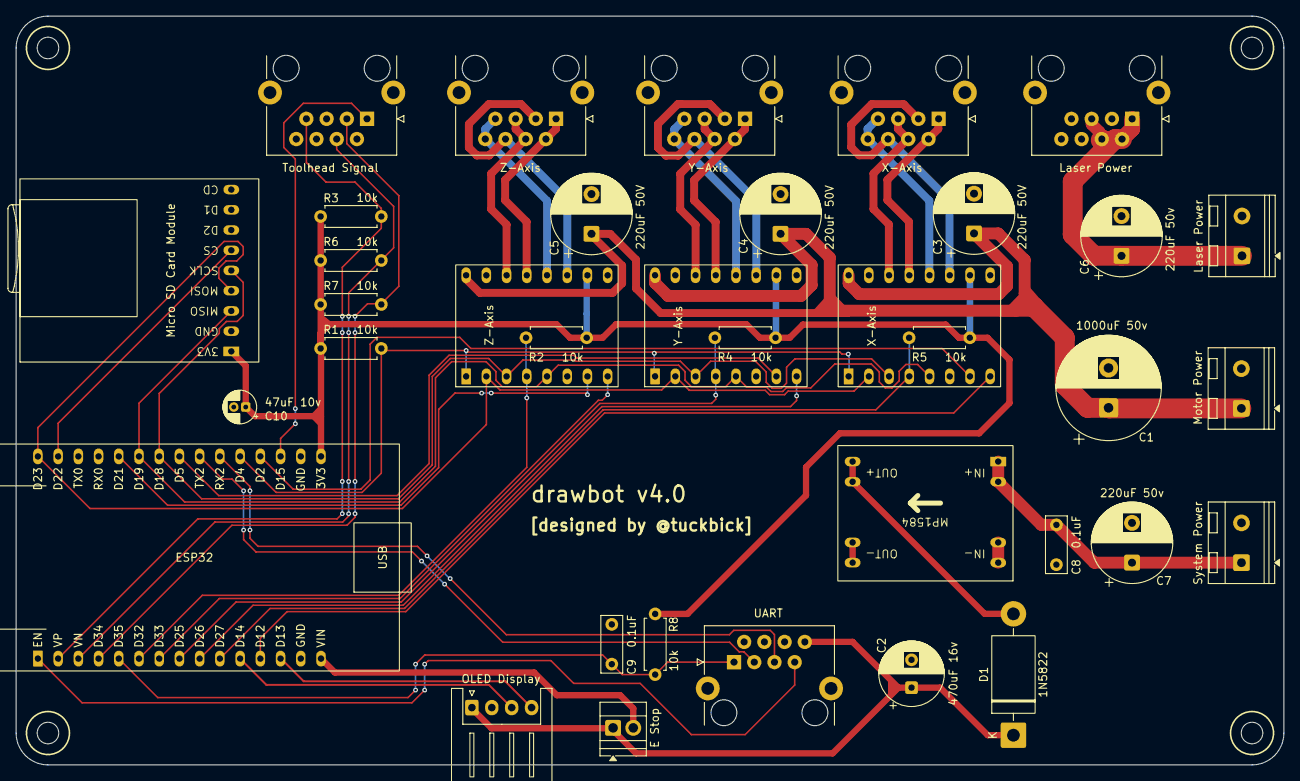
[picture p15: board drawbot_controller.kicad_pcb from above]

Board: 2 copper layers, 159.2 x 94.0 mm, 36 parts (0 on the bottom side), 44 nets.

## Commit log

2026-03-11 adding belated progress
    [drawbot.kicad_pcb, drawbot.kicad_sch, io_connectors.kicad_sch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]
2026-03-18 rearrange and connect everything
    rearrange and connect everything
    [drawbot.kicad_pcb, io_connectors.kicad_sch, microcontroller.kicad_sch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]
2026-04-01 DRC resolutions; Final silkscreen adjustments;
    [drawbot.kicad_pcb]
2026-04-01 Moving controller project into separate directory
    [drawbot.kicad_pcb, drawbot.kicad_sch, io_connectors.kicad_sch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]
2026-04-02 rename controller project files
    [drawbot_controller.kicad_pcb, drawbot_controller.kicad_sch]
2026-04-02 add rj45 to stepper connection boards
    [drawbot_stepper.kicad_pcb, drawbot_stepper.kicad_sch]
2026-04-02 clean up stepper board
    [drawbot_stepper.kicad_pcb, drawbot_stepper.kicad_sch]
2026-04-02 add frame and gantry boards
    [drawbot_frame_hub.kicad_pcb, drawbot_frame_hub.kicad_sch, drawbot_gantry_hub.kicad_pcb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]
2026-04-02 add stepper board production files
2026-04-02 add frame board production files
2026-04-02 add gantry board production files
2026-04-02 removing custom symbols and footprints
